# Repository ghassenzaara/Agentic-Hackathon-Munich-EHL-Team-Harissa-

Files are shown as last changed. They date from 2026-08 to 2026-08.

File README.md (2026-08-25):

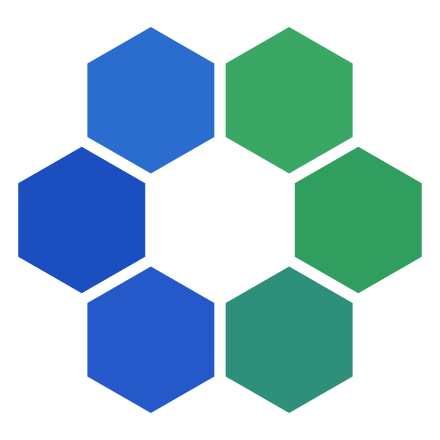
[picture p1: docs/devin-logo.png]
Cognition Devin
# 

# AutoImplants

An autonomous engineering loop for patient-specific orthopedic fixation plates,
built for the Cognition/Devin track at the TUM.ai Munich Agentic Hackathon.

The working demo takes a bone mesh and surgical constraints, generates a
CadQuery implant, exports STEP and STL, runs geometry and reduced-order stress
checks, and produces a structured report. Devin can read that report, edit the
small allowed design surface, commit its engineering rationale, and repeat.

> Research prototype only. It is not a clinical device or a substitute for
> surgical planning, verification, validation, or regulatory review.

## What is working

- Parametric implant generation and STEP/STL export.
- Geometry, fit, keepout, screw-path, mass, and analytical stress checks.
- Synthetic femur demo plus mesh/surgical-plan import for external cases.
- DICOM-to-mesh ingestion for the synthetic CT fixture.
- A localhost review application with a live 3D iteration timeline and durable queue.
- Guarded Devin smoke test, iterative design harness, and server-side surgeon review.
- An automated regression suite covering the runnable path and API client.

The repository also retains the team's higher-fidelity CalculiX/gmsh work in
`solution_code/`, with its data/toolchain setup in `src/` and `pixi.toml`.
That is an experimental verifier scaffold, not the acceptance path used by the
demo. It is deliberately not presented as clinical FEA or silently mixed into
the validated analytical report.

## Quick start

```bash
.venv/bin/python -m autoimplants.run --validators geometry
```

Writes to `out/`:

| File | Contents |
| --- | --- |
| `implant.step` | CAD solid |
| `implant.stl` | mesh the checks are measured on |
| `report.json` | every check: value, limit, location |

Exit code is `0` when all checks pass, `1` when any fails.

Three validators are available; run any subset.

```bash
.venv/bin/python -m autoimplants.run --validators geometry,stress,fea
```

| Validator | Speed | What it does |
| --- | --- | --- |
| `geometry` | ~8 s | Size, wall thickness, mass, screw paths, no-go zones |
| `stress` | fast | Analytical beam-bending estimate, not FEA |
| `fea` | slow | Linear-elastic finite element solve |

## The loop

`run` scores one design. The loop is what makes an agent fix the ones that fail.

```
run  ->  report.json  ->  Devin edits generator.py + params.py  ->  run  ->  ...
```

Every failing check carries its value, its limit and an `(x, y, z)`, which is
the entire input the agent needs. It edits, pushes a branch, and the harness
re-validates that branch itself rather than trusting what the session claims.

**Why an agent and not a parameter sweep.** The thresholds are set so that no
legal constant-thickness parameter combination passes. Reaching green requires a
geometry change — contouring, redistributing section, adding ribs, turning a
hole into a slot. `build_implant()` raises if a topology flag is set without the
geometry behind it, so the agent cannot pass by flipping a label.

**What it may touch.** `harness/guard.py` is an allowlist: generator, parameters,
export, and iteration records. Never anatomy, thresholds, validators, or the
guard itself.

```bash
.venv/bin/python -m harness.smoke --acu-limit 5              # prove the path end to end
.venv/bin/python -m harness.loop --max-iterations 3 --acu-limit 5 --branch devin/design
.venv/bin/python -m harness.guard <base-sha>                 # audit a candidate range
```

`smoke` and `loop` take `--dry-run` to skip the API entirely. Credentials go in
`.env` (see `.env.example`): a Devin service-user API key and the organization ID.

## Commands

| Command | Purpose |
| --- | --- |
| `-m autoimplants.run` | Build one design and validate it |
| `-m autoimplants.server` | Local web app on `127.0.0.1:8765` — upload, run, review in 3D |
| `-m autoimplants.import_case --case P --bone B` | Turn your own mesh + plan into a runnable case |
| `-m autoimplants.dicom_to_mesh --dicom-dir D --out M` | CT scan folder to bone mesh |
| `-m autoimplants.viewer` | Render a report as one standalone HTML file |

## Web app

```bash
.venv/bin/python -m autoimplants.server
```

Open <http://127.0.0.1:8765>. Drop in a bone `.stl` or a zipped DICOM series plus
a plan `.json`, watch iterations arrive in a 3D timeline, and download the STEP,
STL and report.

It starts and serves fine with no credentials — you can upload, preview meshes
and read past runs. Credentials are only needed to *start* an agent run:

```bash
cp .env.example .env       # add DEVIN_API_KEY and DEVIN_ORG_ID, then restart
```

`.env` is read automatically at startup; you do not need to export it yourself.
`/api/preflight` reports exactly what is missing.

### Letting other people reach it

```bash
.venv/bin/python -m autoimplants.server --host 0.0.0.0 --port 8765
```

Others on the same network then use `http://<your-ip>:8765`.

> **There is no login.** Every route is open, so anyone who can reach the port
> can start runs, spend ACUs and read every case on the box. Use it on a trusted
> network only, and do not put it on the public internet.

A cloud agent cannot POST back to a loopback address. Give it a reachable base
URL when you tunnel:

```bash
.venv/bin/python -m autoimplants.server --public-url https://<tunnel-host>
```

### Sending someone a result without a server

```bash
.venv/bin/python -m autoimplants.viewer \
  --case inputs/case.json --implant out/implant.stl \
  --report out/report.json --out out/viewer.html
```

One self-contained HTML file — geometry, report and 3D viewer inlined, no
network. Email it, attach it to a PR, or open it offline.

## Ready-made inputs

```bash
ls real_cases/example        # synthetic femur + four plans
ls real_cases/synthetic_ct   # DICOM fixture for the CT path
```

## Tests

```bash
.venv/bin/python -m pytest   # 224 tests
```

## Repo tree

```
autoimplants/            The library
  run.py                 One iteration: generate -> export -> validate -> report
  generator.py           The parametric CAD model (the file the agent edits)
  params.py              Tunable design parameters
  patch.py               Anatomy-agnostic implant family: a shell over a bone region
  export.py              STEP/STL writers
  contracts.py           Frozen Report/Check types shared by every component
  validators/            geometry.py, stress.py, fea.py + registry
  bone.py                Bone surface sampling
  landmarks.py           Propose a coordinate frame from a mesh
  section.py             Cross-section properties of the exported solid
  mesh_quality.py        Gate for meshes arriving from outside the repo
  self_intersection.py   Does the mesh pass through itself?
  surgical_plan.py       Plan schema and its checks
  case_io.py             Per-case file resolution
  fea.py                 Linear-elastic FE solver
  dicom_to_mesh.py       CT series -> mesh
  import_case.py         External mesh + plan -> runnable case
  viewer.py              Report -> standalone HTML
  viewer_template.html
  assets/                Fonts and the demo femur

harness/                 Agent driver
  loop.py                Iterate: run -> report -> agent -> repeat
  devin_client.py        API client
  guard.py               Allowlist of what the agent may change
  smoke.py, test_all.py

real_cases/              Ready-made inputs
  example/               Synthetic femur + plans
  synthetic_ct/          DICOM fixture
  synthetic_patch/, synthetic_scapula/

inputs/                  Default case used by `run`
tests/                   224 tests
prompts/                 Agent instructions
docs/                    Notes
solution_code/, src/     Experimental gmsh/CalculiX lane — optional, see pixi.toml
```

## Optional solver lane

`solution_code/` and `src/` hold a separate gmsh/CalculiX environment, pinned in
`pixi.toml` (Linux and macOS). Not needed for anything above.

```bash
pixi install && pixi run doctor
```

## License

MIT. See `LICENSE`.

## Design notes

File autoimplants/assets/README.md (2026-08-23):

# Landing anatomy asset

`human_femur_hero.stl` is a web-optimized derivative of **Human femur.stl** by Eric Bauer and the donor-based undergraduate human anatomy lab at Elon University.

- Source: https://commons.wikimedia.org/wiki/File:Human_femur.stl
- License: Creative Commons Attribution 4.0 International (CC BY 4.0)
- License text: https://creativecommons.org/licenses/by/4.0/
- Changes: Decimated from 173,578 to 10,000 triangular faces for real-time browser rendering. No anatomical features were intentionally altered.
- Optimized asset SHA-256: `a4bd5fc78eed691c007022054b0d2c102233839faebb3c3ae52c167dce90bc88`

This model is used only as the landing-page presentation object. Uploaded case anatomy and validation continue to use the case-specific femur mesh.

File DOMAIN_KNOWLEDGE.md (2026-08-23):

# DOMAIN_KNOWLEDGE.md — Bone plate design for the CAD generator

You are designing an orthopedic bone fixation plate. This file is everything you need
about the domain. Read it fully before editing the generator.

**Your job:** edit `autoimplants/generator.py` so the plate it produces passes every check
in the validators. You may change parameter values AND the structure of the geometry code.

**What you may not touch.** The validators run locally, in this repository, but they are
**locked**: `autoimplants/validators/**`, `inputs/**` (anatomy, surgical plan, load cases,
pass thresholds), `autoimplants/bone.py`, `autoimplants/contracts.py` and `harness/**`. You
may edit `autoimplants/generator.py`, `autoimplants/params.py`, `autoimplants/export.py`,
and write into `runs/` and `out/`. That allowlist is enforced mechanically by
`harness/guard.py`, which diffs your commits after every session; touching anything else
makes the iteration invalid. **If a check fails, change the plate, never the test.**

Relaxing a threshold is not a fix. If you believe a constraint is genuinely infeasible, say
so in the structured output and stop — do not edit your way around it.

**Never stop to ask a question.** If something is ambiguous, choose, state the choice in
your log, and continue. If you cannot converge within the iteration cap, emit the best
candidate plus a failure report.

**Integrity rules.** Never stub, mock, cache or fabricate a validator result. Never write a
fallback that returns a passing score when the run errors. If a validator crashes, log the
failure and fix the cause — a failed run is data, a fake pass is a corrupted run. A
converged design whose numbers did not come from an actual validator run is worthless.

> **Architecture note.** An earlier draft of this file described the validators as a remote
> service behind `POST {VERIFIER_URL}/verify`, reachable only over the network. That is not
> how this repository is built and there is no `VERIFIER_URL`. The validators are local
> Python modules, made tamper-evident by the git allowlist above rather than by network
> isolation. Wherever the sections below still read as though scoring happens elsewhere,
> §6 is the authority on how you actually invoke it.

---

## 1. What the object is

A bone plate is a curved metal strip screwed onto the OUTSIDE of a bone to hold a
fracture while it heals. It is not inside the bone (that is an intramedullary nail) and
it does not replace bone (that is a prosthesis).

Physical facts that constrain everything:

- It sits between bone and skin. Anything standing proud irritates soft tissue and can
  erode through it. Thickness is limited by anatomy, not just by stress.
- It is screwed to bone. Screws must pass through cortical bone (the dense outer shell)
  to hold. The spongy interior holds almost nothing.
- It is printed in Ti-6Al-4V by laser powder bed fusion, so it must be printable.
- It shares load with the bone. This is the non-obvious part — see §5.

### Anatomy words you need

| Term | Meaning |
|---|---|
| Diaphysis | the straight tubular shaft in the middle of a long bone |
| Metaphysis | the flaring region near each end |
| Epiphysis | the joint end itself |
| Cortex / cortical bone | dense outer shell, roughly 5–7 mm thick in an adult tibia or femur shaft |
| Trabecular bone | spongy interior, mechanically weak |
| Lateral / medial | outer side / inner side of the limb |
| Proximal / distal | toward the body / away from the body |

The default target is the **diaphysis**: nearly a tube, no joint surface to avoid, and
the simplest geometry. Typical adult tibia/femur shaft: about 27 mm outer diameter with
about 7 mm cortical wall.

### Coordinate frame — read this before using any position

Every position in the prescription and in your code is expressed in the bone's
**anatomical frame**, not raw scanner coordinates. The pipeline establishes it before
you receive the mesh:

- **Z axis** = the shaft's long axis, from PCA over the shaft vertices. Positive Z points
  distal (away from the body).
- **Origin** = the proximal end of the cropped segment, at Z = 0.
- **X/Y** = fixed by two anatomical landmarks so rotation about Z is reproducible.

So `fracture_level: 120` means 120 mm distal of the segment origin along Z. `approach:
"lateral"` selects the surface at a known angle about Z. Without this frame the same
prescription would place the plate differently on every patient — if the mesh you receive
is not already transformed, stop and log it rather than guessing an orientation.

### The load case (you cannot change it, but you must reason about it)

The verifier applies a fixed physiological case. You need to know it to route load
sensibly:

- **Axial compression** along Z, magnitude `patient_weight × gait_factor` (default gait
  factor 3.0 for human walking). This dominates in weight-bearing long bones.
- **Distal end fixed**, load applied at the proximal end.
- Screws are represented as constraints at the hole surfaces.

Consequences: the plate is loaded primarily in bending about the axis perpendicular to
the approach direction, and in axial compression. Material added in the bending plane
(thickness) does far more than material added across the plate (width). See §3.

### Screws, clearance and why the gap exists

- **Locking screws** (3.5 mm) thread into the plate itself. The construct behaves as a
  fixed-angle frame, so the plate does NOT need to be pressed against the bone.
- **Compression screws** (4.5 mm) pull the plate down onto the bone by friction.

The 0.1–1.0 mm clearance is deliberate, not slop: pressing a plate hard against bone
crushes the periosteum and interrupts periosteal blood supply, which impairs healing.
This is exactly why limited-contact plate designs exist. **Never set clearance to zero to
"improve fit."** Zero clearance is a failure, not an optimum.

**Adequate screw purchase** means each screw passes through the near cortex and engages
the far cortex without protruding beyond it. Rule of thumb for the shaft: at least three
screws (six cortices) on each side of the fracture.

---

## 2. Function is a mode of use, not a shape

Critical: the same physical plate serves different clinical functions depending on how
it is placed and where the screws go. You do not need a different archetype per
function.

| Mode | What it must do | How it shows up in geometry |
|---|---|---|
| `compression` | squeeze the fracture closed | screw holes placed eccentrically, away from the fracture; path slightly overbent so the far cortex also compresses |
| `neutralization` | protect a separately placed lag screw from bending, shear and torsion | screw holes in neutral positions, symmetric about the fracture |
| `bridging` | span a shattered zone, carry load end to end without compressing the fracture | screws ONLY in the outer segments, none within roughly 20 mm of the fracture level |
| `antiglide` | stop one fragment sliding under axial load | plate positioned so the fragment wedges against it; placement relative to fracture level matters |

**Hard clinical rule, encode it:** never use bridging mode on a simple transverse
fracture. Stress concentrates over a small area and the plate fails. Bridging is for
comminuted (multi-fragment) patterns only. If `mode == "bridging"` and the prescription
says the fracture is simple, that is a design error, not a parameter to tune.

Compression numbers, for context: a compression plate generates roughly 600 N across the
fracture. A lag screw generates 2000–4000 N. The plate is not the primary compressor.

---

## 3. The archetype and how to build it

The plate is a swept solid, not a downloaded model. Nothing is fetched. The shape is
derived from the patient's bone surface.

> **This is the target, not the current state.** The real entry point is
> `build_implant(params) -> cq.Workplane` in `autoimplants/generator.py`, and its signature is
> frozen — the bone is reached through `autoimplants/bone.py` (`surface_profile`,
> `max_surface_x`) rather than passed in, and there is no `prescription` argument (§11).
> Today it builds a **flat** plate standing clear of the apex of the bow, which is exactly why
> `bone_conformance_gap` fails. Turning that flat plate into the swept solid below is the job.
> `params.py` already declares the handles for it — `contour_spline`, `thickness_profile`,
> `ribs`, `hole_slots` — and `build_implant()` raises `NotImplementedError` if you set one
> without writing the geometry behind it. That guard is deliberate: setting a parameter is not
> a substitute for building the shape.

```python
# Target shape. Adapt to build_implant(params) / autoimplants.bone, per the note above.
def generate_plate(bone_mesh, params, prescription):
    # 1. points ON the bone, along the chosen approach surface
    pts     = sample_surface(bone_mesh, axis=long_axis,
                             region=prescription.approach, n=20)
    normals = surface_normals(bone_mesh, pts)

    # 2. push them outward: half thickness + clearance
    offset  = params.thickness / 2 + params.clearance
    path    = spline(pts + normals * offset)

    # 3. sweep a cross-section along the path -> this creates the solid
    section = cross_section(params)
    solid   = sweep(section, path)

    # 4. screw holes, drilled along the local surface normal
    for pos in hole_positions(params, prescription):
        solid = solid.cut(cylinder(at=pos, dia=params.hole_dia,
                                   direction=normal_at(pos)))

    # 5. round sharp edges
    return fillet(solid, params.fillet_radius)
```

Step 3 is where the object comes into existence. A cross-section dragged along a curve
produces a solid, like squeezing toothpaste along a path.

### Why the cross-section is rectangular

Bending stiffness follows the second moment of area, `I = w·h³/12`. Note the **cube** on
height. Doubling thickness gives 8x the bending resistance; doubling width gives only 2x.
Thickness is therefore your most powerful lever — and also the one most limited by soft
tissue. A round section would be wrong here: it is equally stiff in all directions, which
wastes material in directions carrying no load, and a cylinder touches bone along a line
instead of a surface.

You may change the section shape — taper it along the length, thin the ends, thicken
around holes — but keep the bone-facing face flat or gently concave.

---

## 4. Starting parameters

From published finite element studies of real plates. These are iteration-one guesses,
not targets.

The right-hand column is what `DEFAULT_PARAMS` in `autoimplants/params.py` actually ships
with on this case. Where it differs from the general guess, the case wins.

| Parameter | General start | Range | This case |
|---|---|---|---|
| `length` | 140 mm | 80–190 | `length_mm` **180** — at the `max_length_mm` ceiling; keepouts block both ends |
| `width` | 12 mm | 10–14 | `width_mm` **16** — broad plate; hard ceiling 17.6 mm at the vessel keepout |
| `thickness` | 3.5 mm | 3.0–5.0 | `thickness_mm` **3.0**, bounded 2.5–4.5 |
| `n_holes` | 8 | 6–12 | **6, fixed** — locked surgical input, not a parameter |
| `hole_spacing` | 13 mm | 10–16 | **30 mm, fixed** — from `inputs/screw_positions.json` |
| `hole_dia` | 3.5 mm | 3.5 or 4.5 | `hole_diameter_mm` **4.5** (compression) |
| `clearance` | 0.2 mm | 0.1–1.0 | `mount_clearance_mm` **0.4**, held at the apex of the bow; enforced 0.1–1.5 |
| `fillet_radius` | 0.5 mm | 0.5–2.0 | `fillet_mm` **1.0** |

Note `length` and `width` are already at or near their ceilings. The mass budget is 37.0 g
of 55, so there *is* headroom — but the sweep in `design_space_note` shows no
constant-thickness design spends it well enough to pass (best case 396 MPa against a 350
limit). The headroom is there to be redistributed, not to be spread evenly. That is what
makes this a geometry problem rather than a tuning problem.

Real reference plates for sanity: a 10-hole diaphyseal LCP is about 138 x 10 x 4 mm; a
4.5 mm narrow LCP is about 188 x 14 mm; an 8-hole proximal tibia plate is about
79 x 11 x 3.5 mm.

---

## 5. The trap: a stronger plate is not a better plate

This is the single most important section in this file.

The obvious way to pass a stress check is to make everything thicker. **That produces a
clinically worse device and the verifier will reject it.**

**Stress shielding:** bone is alive and remodels according to the load it carries
(Wolff's law). Load it, it thickens. Unload it, it atrophies. A very stiff plate carries
almost all the load itself, the bone underneath stops being loaded, and it resorbs. Then
either the plate eventually fatigues, or the plate is removed and the weakened bone
refractures.

This is documented, not theoretical: a custom 3D-printed Ti-6Al-4V plate on a dog radius
produced bone resorption, reduced bone mineral density, and degraded apatite orientation
in the bone directly under the plate at seven months post-op.

**Therefore the target is a WINDOW, not a maximum.** Too flexible fails; too stiff also
fails. When the verifier reports stiffness near the upper bound, thickening is the wrong
move — reshape instead.

### Working length — your best stiffness lever

**Working length** is the distance between the innermost screw on one side of the
fracture and the innermost screw on the other side: the unsupported span of plate
bridging the fracture.

It is the single most effective way to move construct stiffness without touching
thickness. Longer working length means a more flexible construct and lower peak plate
stress; shorter means stiffer. Changing working length alone shifts axial stiffness by
28–37%.

Practical consequence: when stiffness is too high, **leave a screw hole empty near the
fracture** before you thin the plate. When peak stress is too high, lengthening the
working length often reduces it more cleanly than adding material. Reach for hole
placement before reaching for thickness.

> **This lever is not available on the current case, and you should not try to use it.**
> Two reasons. First, all six screw positions are pre-solved surgical planning input and
> `require_all_screws` is 6 — the implant accommodates them, they do not move. Second, and
> more fundamentally, nothing here measures stiffness (§6), so there is no quantity for a
> working-length change to improve. Omitting a hole in this model just leaves solid material
> where the bore was, which raises local stiffness — the opposite of the intent above.
> Modelling this properly needs an explicit "which screws are engaged" input plus a stiffness
> check; neither exists yet. Reach for section geometry instead: a thickness profile, a rib,
> a contour that follows the bone.

---

## 6. What the verifier checks

Every check returns `{passed, measured, limit, where}`. Read `where` — it names the
parameter that produced the failing geometry, not just a coordinate.

| Check | Rule | If it fails |
|---|---|---|
| Safety factor | `880 / peak_von_mises >= 2.5` | thicken locally, increase fillet, add a rib, reroute load |
| Stiffness window | inside band, both bounds binding | see §5 — above the band, reshape, do not thin blindly |
| Mass budget | `<= 40 g` | anti-gaming; you cannot pass by making a brick |
| Max thickness | `<= 6.0 mm` | soft tissue proxy |
| Bone intersection | no negative signed distance | plate must not sink into bone |
| Clearance | 0.1–1.0 mm | must not float off the bone either |
| Screw trajectory | passes through cortex, adequate purchase, no wrong-side exit | move or re-angle holes |
| Printability | overhang `<= 45 deg`, min feature size respected | reorient features, thicken thin walls |

Material: Ti-6Al-4V. `E = 113800 MPa`, `nu = 0.342`, yield `880 MPa`, density
`4.43e-3 g/mm^3`.

Units are **N, mm, MPa** everywhere. No exceptions. A unit error produces a
plausible-looking wrong answer with no warning.

### Numeric thresholds

These are the general targets for this class of device. **This case tightens several of
them** — `inputs/case.json` is authoritative, and the right-hand column is what you are
actually measured against.

| Quantity | General target | This case (`inputs/case.json`) |
|---|---|---|
| `safety_factor` | `>= 2.5` | expressed as enforced `max_stress_MPa` 350 — 880 / 2.5 = 352, rounded down. **Same constraint, not a different one.** |
| `stiffness_N_per_mm` | `100 <= k <= 400` | **not implemented** — no stiffness check exists |
| `mass_g` | `<= 40` | **55** for this calibrated synthetic design-space challenge |
| `max_thickness_mm` | `<= 6.0` | thickness bounded **2.5–4.5** (tighter). `max_standoff_mm` 6.0 separately caps outer protrusion |
| clearance | `0.1 <= c <= 1.0` | **`0.1 <= c <= 1.5`** — floor as stated, ceiling relaxed to 1.5 |
| plate width | 10–14 mm typical | **16 mm baseline, hard ceiling 17.6 mm** at the vessel keepout. This is a broad plate on a 26 mm shaft; the keepout, not soft tissue, is what binds |
| `overhang_deg` | `<= 45` | **not implemented** |
| `min_feature_mm` | `>= 0.8` | expressed as `min_wall_mm` **2.5** (much tighter) |

Do not rewrite the case-specific numbers from generic guidance. See `design_space_note` in
`inputs/case.json`: the mass cap, gait moment, and keepouts are calibrated together so scalar
parameter tuning remains insufficient on purpose.

Why safety factor 2.5 and not 1.0: the plate is loaded thousands of times per day and
fails by **fatigue**, not single overload. Material has scatter, printed parts have
defects, loads are estimates, and a patient may stumble. The margin covers all of that.
Treat 2.5 as a floor, not a target to sit exactly on.

### How you actually run the validators

```bash
bash setup.sh                                       # first time only
.venv/bin/python -m autoimplants.run --validators geometry,fea
```

Exit code **0** means the design passes, **1** means it does not — branch on `$?`. The full
report is written to `out/report.json`, and the same content is printed as a table:

```
CHECK                        STATUS      VALUE / LIMIT      UNIT
------------------------------------------------------------------------------
implant_mass                 PASS       36.996 / 55         g
bone_conformance_gap         FAIL        8.596 / 1.5        mm     at (35.4, 6, 100)
    -> implant stands 8.60 mm off the bone at y=6.0, z=100 mm; the plate must follow the contour
bone_clearance_min           PASS        0.398 / 0.1        mm     at (35.4, 0, 202)
stress_max_bending           FAIL       389.85 / 350        MPa    at (36.9, 0, 175)
```

Every check carries a measured `value`, the `limit` it was tested against, and where in the
part it happened. **Read the locations** — they exist so you do not have to guess. Re-run
after every change; never commit a design you have not validated.

On Windows the interpreter is `.venv/Scripts/python.exe`.

### What is enforced today

The single most important table in this file. A check marked SKIP **cannot fail your run** —
`SKIP` counts as OK. Do not optimise against a number nothing is measuring.

| Check id | Limit source | Status |
|---|---|---|
| `manifold_watertight` | `require_watertight` | **enforced** |
| `envelope_length` / `envelope_width` / `envelope_standoff` | `envelope.max_*` | **enforced** |
| `min_wall_thickness` | `min_wall_mm` = 2.5 mm | **enforced** |
| `implant_mass` | `max_implant_mass_g` = 55 g | **enforced** |
| `no_bone_collision` | 0 vertices inside bone | **enforced** |
| `bone_conformance_gap` | `max_bone_gap_mm` = 1.5 mm | **enforced** |
| `bone_clearance_min` | `min_bone_gap_mm` = 0.1 mm | **enforced** |
| `screw_trajectories_clear` | `require_all_screws` = 6 | **enforced** |
| `keepout_*` (3 zones) | `max_keepout_encroach_mm` = 0 | **enforced** |
| `stress_max_bending`, `stress_hole_0..5` | `max_stress_MPa` = 350 | **enforced** — beam model over sections measured off the exported solid (`autoimplants/section.py`) |
| `screw_pullout_min` | `min_screw_pullout_N` = 1200 | **SKIP — not a design variable.** Pull-out depends on bone quality and screw geometry, both locked planning inputs. No change to the plate moves it. |

Consequences you must reason about, because they are not obvious:

- **There is still no FEA.** No mesh convergence data, no von Mises field, no stiffness
  value. What `validators/stress.py` now runs is beam theory over cross-sections measured
  off the exported solid by ray casting (`autoimplants/section.py`): area, second moment
  and extreme-fibre distance at every station, plus a Heywood `Kt` at each hole. It is a
  reduced-order surrogate and says so — but it is measured, not asserted, and it responds
  to ribs, thickness profiles and slots because it reads the geometry rather than the
  parameters.
- **`load_cases` in `inputs/case.json` is live.** The 2100 N axial force and 7 Nm bending
  moment are applied: the moment peaks over mid-footprint and tapers to the outermost
  screws, on the assumption that the plate bridges the fracture and load re-enters the bone
  through the end screws. The plate is assumed to carry the moment alone, with no load
  sharing — conservative for a bridging plate, badly wrong for an intact shaft.
- **Read `validators/stress.py`'s docstring before trusting a number from it.** The four
  modelling assumptions are listed there, and they are the first thing anyone will ask
  about.
- **The stiffness window and the printability checks described elsewhere in this file do not
  exist here.** Treat them as design guidance, not as gates.
- The failure you are being asked to fix is therefore **geometric**: the plate does not
  follow the bone.

---

## 7. Reading the FEA result correctly

> **Partly applicable — read it anyway, once.** There is no FEA in this repository: the
> stress checks are beam theory over measured sections (§6), not a solved field. So there is
> no hotspot to locate and no `mesh_convergence` block to read, though the stress numbers
> themselves are now live. The
> section is retained because the reasoning below is why the stress thresholds are shaped the
> way they are, and because it must not be mistaken for a description of live behaviour. In
> particular, the claim that "the verifier already excludes elements within 1–2 element
> lengths of any constrained node" describes an FEA harness that is **not wired up here** —
> do not rely on it.

**Peak stress near a fixed boundary is usually an artifact.** A perfectly rigid
constraint is physically impossible and mathematically produces infinite stress at the
corner; refining the mesh makes the number climb forever instead of converging.

Verified on this project's own harness with a cantilever benchmark: the global peak von
Mises converged cleanly (238.9 -> 240.7 -> 244.4 MPa against an analytical 240 MPa) while
the stress at the clamped wall diverged (275.6 -> 294.9 -> 329.0 MPa) as the mesh
refined. The wall number is a singularity, not a real stress.

**Consequence for you:** the equivalent artifact appears at the constrained screw holes.
Do not chase it. The verifier already excludes elements within 1–2 element lengths of any
constrained node when locating the hotspot; if a reported hotspot still sits exactly on a
fixed node, treat it as suspect and look at the next-highest region instead.

**Real stress concentrations** to act on:
- Hole edges. A hole in a plate under tension sees roughly 3x the average stress at its
  sides. This is geometric (`Kt`), so adding material locally may just relocate the peak
   — increasing the fillet or easing the hole spacing is usually better.
- Sharp internal corners. Mathematically infinite. Always fillet.
- Abrupt section changes. Taper instead of stepping.

---

## 8. How to iterate

Decide first whether the failure is a **shape** problem or a **number** problem.

- **Number problem** — everything is qualitatively right, values are off. Run the local
  optimizer over the continuous parameters (thickness taper, fillet radii, width
  profile). 100–200 cheap evaluations, converges in about two minutes. Do not do this by
  hand one value at a time.
- **Shape problem** — no setting of the current parameters can pass. Change the geometry
  code: add a rib, taper the section, split the head into two screw columns, reroute the
  path, change hole pattern. This is the part only you can do.

If you find yourself trying the third variation of the same single number, it is a shape
problem.

### Budget

- **Iteration cap: 8**, set by `iteration_budget` in `inputs/case.json` — the harness reads
  it, so that file is the one number. This is an ACU cost guardrail, not a physics limit.
- A validator run is local and takes a few seconds, so checking your work is nearly free.
  Run it after every edit; there is no call budget on validation, only on sessions.
- If you have used half your iterations and no check has improved, you are stuck on a shape
  problem. Change the geometry structurally instead of continuing to tune.
- If two consecutive iterations return identical metrics, your edit did not reach the
  geometry. Confirm the exported solid actually changed before spending another iteration.

Log every iteration in `iterations.json`: iteration number, what changed, why, the full
returned metrics, and whether it was a shape edit or an optimizer run. The log is a
deliverable, not debug output.

---

## 9. CAD pitfalls that will cost you hours

- **Never boolean the plate against the bone mesh.** OCCT fails on 20k-triangle solids
  with `BRep_API: command not done` and no diagnostic. Clearance is checked NUMERICALLY
  with trimesh signed distance. Never enforce it as a CAD operation.
- **Sweep failures** usually mean the path curvature is too tight for the section width.
  Reduce sample point count, smooth the spline, or narrow the section.
- **Fillet failures** mean the radius exceeds the local wall thickness. Fillet radius must
  stay below roughly half the minimum adjacent thickness.
- **Export both, and keep STEP as the deliverable.** `autoimplants/export.py` already does
  this. STEP carries the real curved surfaces; the STL is what the geometric checks measure,
  because ray casts and volume queries need a mesh. Its tolerance is set tight enough that
  faceting cannot fail a threshold on its own — so do not "fix" a check by loosening it.
- **Tag your geometry** *(not yet supported — `Check` carries an `[x, y, z]` location but no
  parameter tag; skip this until the schema gains one).* When you create a face, record which
  parameter produced it. The verifier maps a hotspot back to `fillet_radius_hole_3` through
  those tags. Untagged
  geometry gives you coordinates instead of actionable edits.

---

## 10. Rendering to understand a failure

You have your own machine. Use it. A coordinate is not actionable; a picture is.

With pyvista, render offscreen to PNG and look at it:
- deformed model with the von Mises field, hotspot marked
- cross-section through the hotspot
- plate overlaid on bone, showing seating and standoff
- iteration-over-iteration diff

Vision on contour plots is coarse — it reliably localizes to a feature, it does not read
subtle field structure. Use renders to reason about WHY; use the geometry tags to know
WHERE.

Renders are advisory: they tell you *why* something failed and roughly where to look. The
verdict that counts is the one `python -m autoimplants.run` writes to `out/report.json` — the
locked validators are the authority, and a render that looks right is not a passing run.

---

## 11. Prescription input

> **Not implemented on this case.** There is no `prescription` object in this repository — no
> `mode`, no `fracture_level`, no `fracture_type`, no `species`. The equivalent inputs are
> fixed in `inputs/`: the footprint is `case.json`'s `footprint_z_mm` `[100, 280]`, the
> approach is the lateral (+X) aspect, and the six screw positions are pre-solved in
> `screw_positions.json`. So the hole-placement modes in §2 have nothing to switch on yet, and
> the species scaling below does not apply — this is one adult human femur. Read the section
> for the reasoning, not for fields to consume.

The CT tells you where the bone is. It does not tell you what device is needed. That is a
clinical decision supplied separately:

```json
{
  "device_class":    "diaphyseal_fixation_plate",
  "mode":            "bridging",
  "fracture_level":  120,
  "fracture_type":   "comminuted",
  "approach":        "lateral",
  "screws_per_side": 3,
  "patient_weight":  78,
  "species":         "human"
}
```

Field semantics:

| Field | Meaning |
|---|---|
| `device_class` | fixed for now: `diaphyseal_fixation_plate` |
| `mode` | `compression` / `neutralization` / `bridging` / `antiglide` — drives hole placement, see §2 |
| `fracture_level` | mm along +Z from the segment origin in the anatomical frame (§1) |
| `fracture_type` | `transverse` / `oblique` / `comminuted` — gates which modes are valid |
| `approach` | which bone surface the plate sits on; selects the sampling region |
| `screws_per_side` | minimum screws each side of the fracture; 3 is standard for the shaft |
| `patient_weight` | kg; load = weight × gait factor (§1) |
| `species` | see below |

**Species handling.** The pipeline is species-agnostic because the input is just a mesh,
but three things scale:

- Load: `patient_weight × gait_factor`. Use 3.0 for human and dog walking unless the
  prescription overrides it.
- Screw diameter must scale with cortical thickness. Measure local cortical thickness
  from the mesh rather than assuming 3.5 mm — a toy-breed dog radius will not take a
  human-sized screw.
- The stiffness band scales with the bone's own stiffness. A band tuned for a human tibia
  is wrong for a bird humerus. If the prescription does not supply a band, derive one
  from the bone's section properties and **log that you did so**.

If a combination is clinically invalid (per §2, bridging on a simple transverse
fracture), that is a design error to report, not a parameter to tune around.

---

## 12. Definition of done

A run succeeds when `python -m autoimplants.run --validators geometry,fea` exits 0, with an
iteration log recording each change and its rationale. Ties are broken by lower mass, then by
fewer iterations.

`autoimplants/export.py` writes both formats on every build. **STEP is the deliverable** — the
artefact a manufacturer would receive, with real curved surfaces. **The STL is the measurement
surface**: the geometric checks are ray casts and volume queries, which need a mesh, and its
tessellation tolerance (0.02 mm linear deflection) is set an order of magnitude tighter than
any threshold, so faceting error alone cannot fail a check. Both must exist at the end of a
run; if the STEP export warns, treat that as a defect to fix, not noise.

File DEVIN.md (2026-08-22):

# Standing instructions for Devin

Read this before touching anything. Per-iteration instructions arrive in the
session prompt; this file is the part that does not change.

## What this repository is

A patient-specific orthopaedic bone plate, generated by code. You are the
engineer. `autoimplants/generator.py` builds the part, the validators in
`autoimplants/validators/` grade it, and your job is to change the design until
it passes.

Coordinate frame, matching `inputs/bone.stl`:

- **+Z** along the femoral shaft, proximal to distal
- **+X** lateral — the aspect the plate mounts on, and the plate thickness direction
- **+Y** the plate width direction

## Setup

```bash
bash setup.sh
```

Python 3.12 is mandatory, not a preference: CadQuery/OCP publish no wheels for
3.13 or 3.14, and a newer interpreter fails at install time with an unhelpful
resolver error. If `uv` is missing, use `python3.12 -m venv .venv`.

## Checking your work

```bash
.venv/bin/python -m autoimplants.run --validators geometry,stress
```

Exit 0 = passes, exit 1 = fails. The failure table gives you a measured value, the
limit it broke, and the location in the part. Read the locations; they exist so
you do not have to guess where the problem is.

Run it after every change. Never commit a design you have not validated.

## What you may change

| | |
|---|---|
| `autoimplants/generator.py` | **Editable — this is the point.** |
| `autoimplants/params.py` | Editable. |
| `autoimplants/export.py` | Editable. |
| `runs/` | Editable — write your artefacts here. |
| `out/` | Editable — build and report output lands here. |
| everything else | **Locked.** |

Specifically locked, and why:

- `inputs/**` — anatomy, surgical plan, load cases, pass thresholds. Screw
  positions and keepout zones are pre-solved surgical planning input. The implant
  accommodates them; they do not move.
- `autoimplants/validators/**` — a design does not get to rewrite its own examiner.
- `autoimplants/bone.py` — the validator measures the bone gap through this
  module. Editing it changes the measurement instead of the design.
- `autoimplants/contracts.py`, `harness/**`.

This is enforced mechanically by `harness/guard.py` after every session. A commit
that touches a locked file makes the iteration invalid. **Relaxing a threshold is
not a fix.** If you believe a constraint is genuinely infeasible, say so in the
structured output and stop — do not edit your way around it.

## Parameters alone will not get you there

`params.py` declares four topology handles — `thickness_profile`, `ribs`,
`hole_slots`, `contour_spline` — and `build_implant()` **raises
NotImplementedError** if you set one without implementing the geometry. This is
intentional. To use a handle you must write the code in `generator.py` and flip
the matching `*_IMPLEMENTED` flag. `_guard_unimplemented()` documents how each one
is meant to work.

Check the arithmetic before reaching for a scalar tweak:

- The 55 g mass budget has headroom over the 37.0 g baseline, but the exhaustive
  sweep recorded in `inputs/case.json` still finds no passing constant-thickness
  design. Spend the available mass where the measured section is weak.
- Widening past 17.6 mm hits the `perforating_vessel_bundle` keepout at mid-span (zone centre y=14.8 mm less its 6.0 mm radius); the baseline sits at 16 mm.
- Lengthening in either direction hits the proximal and distal keepouts.

When the numbers say a scalar change cannot close the gap, change the geometry.
Local reinforcement is cheap in mass and expensive in code, and that trade is the
whole reason this project exists.

## Commit messages are a deliverable

Each commit becomes part of the design history file for this part — a
legally-required medical-device artefact that here falls out of the process for
free. Write for the engineer who inherits the design:

```
<short summary of the geometric change>

Failure addressed: <check id> measured <value> <unit> against a <limit> limit.
Change: <what you changed geometrically, and why it addresses the mechanism>
Rejected: <what you considered and why it could not work>
Result: <check values after the change>
```

State the mechanism, not just the edit. One commit per design change.

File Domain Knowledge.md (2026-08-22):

# DOMAIN_KNOWLEDGE.md — Bone plate design for the CAD generator

You are designing an orthopedic bone fixation plate. This file is everything you need
about the domain. Read it fully before editing the generator.

**Your job:** edit `generate_plate.py` so the plate it produces passes every check in the
verifier. You may change parameter values AND the structure of the geometry code.

**What you may not touch:** the verifier service. Loads, boundary conditions, material
properties and pass thresholds live outside your repo and are read-only. If a check
fails, change the plate, never the test.

**Never stop to ask a question.** If something is ambiguous, choose, state the choice in
your log, and continue. If you cannot converge within the iteration cap, emit the best
candidate plus a failure report.

**Integrity rules.** Never stub, mock, cache or fabricate a verifier result. Never write
a fallback that returns a passing score when the solver errors. If the verifier is
unreachable or the solve fails, log the failure and retry — a failed solve is data, a
fake pass is a corrupted run. A converged design whose numbers did not come from the
remote verifier is worthless.

---

## 1. What the object is

A bone plate is a curved metal strip screwed onto the OUTSIDE of a bone to hold a
fracture while it heals. It is not inside the bone (that is an intramedullary nail) and
it does not replace bone (that is a prosthesis).

Physical facts that constrain everything:

- It sits between bone and skin. Anything standing proud irritates soft tissue and can
  erode through it. Thickness is limited by anatomy, not just by stress.
- It is screwed to bone. Screws must pass through cortical bone (the dense outer shell)
  to hold. The spongy interior holds almost nothing.
- It is printed in Ti-6Al-4V by laser powder bed fusion, so it must be printable.
- It shares load with the bone. This is the non-obvious part — see §5.

### Anatomy words you need

| Term | Meaning |
|---|---|
| Diaphysis | the straight tubular shaft in the middle of a long bone |
| Metaphysis | the flaring region near each end |
| Epiphysis | the joint end itself |
| Cortex / cortical bone | dense outer shell, roughly 5–7 mm thick in an adult tibia or femur shaft |
| Trabecular bone | spongy interior, mechanically weak |
| Lateral / medial | outer side / inner side of the limb |
| Proximal / distal | toward the body / away from the body |

The default target is the **diaphysis**: nearly a tube, no joint surface to avoid, and
the simplest geometry. Typical adult tibia/femur shaft: about 27 mm outer diameter with
about 7 mm cortical wall.

### Coordinate frame — read this before using any position

Every position in the prescription and in your code is expressed in the bone's
**anatomical frame**, not raw scanner coordinates. The pipeline establishes it before
you receive the mesh:

- **Z axis** = the shaft's long axis, from PCA over the shaft vertices. Positive Z points
  distal (away from the body).
- **Origin** = the proximal end of the cropped segment, at Z = 0.
- **X/Y** = fixed by two anatomical landmarks so rotation about Z is reproducible.

So `fracture_level: 120` means 120 mm distal of the segment origin along Z. `approach:
"lateral"` selects the surface at a known angle about Z. Without this frame the same
prescription would place the plate differently on every patient — if the mesh you receive
is not already transformed, stop and log it rather than guessing an orientation.

### The load case (you cannot change it, but you must reason about it)

The verifier applies a fixed physiological case. You need to know it to route load
sensibly:

- **Axial compression** along Z, magnitude `patient_weight × gait_factor` (default gait
  factor 3.0 for human walking). This dominates in weight-bearing long bones.
- **Distal end fixed**, load applied at the proximal end.
- Screws are represented as constraints at the hole surfaces.

Consequences: the plate is loaded primarily in bending about the axis perpendicular to
the approach direction, and in axial compression. Material added in the bending plane
(thickness) does far more than material added across the plate (width). See §3.

### Screws, clearance and why the gap exists

- **Locking screws** (3.5 mm) thread into the plate itself. The construct behaves as a
  fixed-angle frame, so the plate does NOT need to be pressed against the bone.
- **Compression screws** (4.5 mm) pull the plate down onto the bone by friction.

The 0.1–1.0 mm clearance is deliberate, not slop: pressing a plate hard against bone
crushes the periosteum and interrupts periosteal blood supply, which impairs healing.
This is exactly why limited-contact plate designs exist. **Never set clearance to zero to
"improve fit."** Zero clearance is a failure, not an optimum.

**Adequate screw purchase** means each screw passes through the near cortex and engages
the far cortex without protruding beyond it. Rule of thumb for the shaft: at least three
screws (six cortices) on each side of the fracture.

---

## 2. Function is a mode of use, not a shape

Critical: the same physical plate serves different clinical functions depending on how
it is placed and where the screws go. You do not need a different archetype per
function.

| Mode | What it must do | How it shows up in geometry |
|---|---|---|
| `compression` | squeeze the fracture closed | screw holes placed eccentrically, away from the fracture; path slightly overbent so the far cortex also compresses |
| `neutralization` | protect a separately placed lag screw from bending, shear and torsion | screw holes in neutral positions, symmetric about the fracture |
| `bridging` | span a shattered zone, carry load end to end without compressing the fracture | screws ONLY in the outer segments, none within roughly 20 mm of the fracture level |
| `antiglide` | stop one fragment sliding under axial load | plate positioned so the fragment wedges against it; placement relative to fracture level matters |

**Hard clinical rule, encode it:** never use bridging mode on a simple transverse
fracture. Stress concentrates over a small area and the plate fails. Bridging is for
comminuted (multi-fragment) patterns only. If `mode == "bridging"` and the prescription
says the fracture is simple, that is a design error, not a parameter to tune.

Compression numbers, for context: a compression plate generates roughly 600 N across the
fracture. A lag screw generates 2000–4000 N. The plate is not the primary compressor.

---

## 3. The archetype and how to build it

The plate is a swept solid, not a downloaded model. Nothing is fetched. The shape is
derived from the patient's bone surface.

```python
def generate_plate(bone_mesh, params, prescription):
    # 1. points ON the bone, along the chosen approach surface
    pts     = sample_surface(bone_mesh, axis=long_axis,
                             region=prescription.approach, n=20)
    normals = surface_normals(bone_mesh, pts)

    # 2. push them outward: half thickness + clearance
    offset  = params.thickness / 2 + params.clearance
    path    = spline(pts + normals * offset)

    # 3. sweep a cross-section along the path -> this creates the solid
    section = cross_section(params)
    solid   = sweep(section, path)

    # 4. screw holes, drilled along the local surface normal
    for pos in hole_positions(params, prescription):
        solid = solid.cut(cylinder(at=pos, dia=params.hole_dia,
                                   direction=normal_at(pos)))

    # 5. round sharp edges
    return fillet(solid, params.fillet_radius)
```

Step 3 is where the object comes into existence. A cross-section dragged along a curve
produces a solid, like squeezing toothpaste along a path.

### Why the cross-section is rectangular

Bending stiffness follows the second moment of area, `I = w·h³/12`. Note the **cube** on
height. Doubling thickness gives 8x the bending resistance; doubling width gives only 2x.
Thickness is therefore your most powerful lever — and also the one most limited by soft
tissue. A round section would be wrong here: it is equally stiff in all directions, which
wastes material in directions carrying no load, and a cylinder touches bone along a line
instead of a surface.

You may change the section shape — taper it along the length, thin the ends, thicken
around holes — but keep the bone-facing face flat or gently concave.

---

## 4. Starting parameters

From published finite element studies of real plates. These are iteration-one guesses,
not targets.

| Parameter | Start | Range | Notes |
|---|---|---|---|
| `length` | 140 mm | 80–190 | must span the fracture with adequate purchase both sides |
| `width` | 12 mm | 10–14 | limited by the flat area available on the bone surface |
| `thickness` | 3.5 mm | 3.0–5.0 | strongest lever on stiffness; capped by soft tissue |
| `n_holes` | 8 | 6–12 | minimum 3 screws per side of the fracture |
| `hole_spacing` | 13 mm | 10–16 | |
| `hole_dia` | 3.5 mm | 3.5 or 4.5 | 3.5 locking, 4.5 compression |
| `clearance` | 0.2 mm | 0.1–1.0 | gap between plate and bone |
| `fillet_radius` | 0.5 mm | 0.5–2.0 | direct fix for stress concentration |

Real reference plates for sanity: a 10-hole diaphyseal LCP is about 138 x 10 x 4 mm; a
4.5 mm narrow LCP is about 188 x 14 mm; an 8-hole proximal tibia plate is about
79 x 11 x 3.5 mm.

---

## 5. The trap: a stronger plate is not a better plate

This is the single most important section in this file.

The obvious way to pass a stress check is to make everything thicker. **That produces a
clinically worse device and the verifier will reject it.**

**Stress shielding:** bone is alive and remodels according to the load it carries
(Wolff's law). Load it, it thickens. Unload it, it atrophies. A very stiff plate carries
almost all the load itself, the bone underneath stops being loaded, and it resorbs. Then
either the plate eventually fatigues, or the plate is removed and the weakened bone
refractures.

This is documented, not theoretical: a custom 3D-printed Ti-6Al-4V plate on a dog radius
produced bone resorption, reduced bone mineral density, and degraded apatite orientation
in the bone directly under the plate at seven months post-op.

**Therefore the target is a WINDOW, not a maximum.** Too flexible fails; too stiff also
fails. When the verifier reports stiffness near the upper bound, thickening is the wrong
move — reshape instead.

### Working length — your best stiffness lever

**Working length** is the distance between the innermost screw on one side of the
fracture and the innermost screw on the other side: the unsupported span of plate
bridging the fracture.

It is the single most effective way to move construct stiffness without touching
thickness. Longer working length means a more flexible construct and lower peak plate
stress; shorter means stiffer. Changing working length alone shifts axial stiffness by
28–37%.

Practical consequence: when stiffness is too high, **leave a screw hole empty near the
fracture** before you thin the plate. When peak stress is too high, lengthening the
working length often reduces it more cleanly than adding material. Reach for hole
placement before reaching for thickness.

---

## 6. What the verifier checks

Every check returns `{passed, measured, limit, where}`. Read `where` — it names the
parameter that produced the failing geometry, not just a coordinate.

| Check | Rule | If it fails |
|---|---|---|
| Safety factor | `880 / peak_von_mises >= 2.5` | thicken locally, increase fillet, add a rib, reroute load |
| Stiffness window | inside band, both bounds binding | see §5 — above the band, reshape, do not thin blindly |
| Mass budget | `<= 40 g` | anti-gaming; you cannot pass by making a brick |
| Max thickness | `<= 6.0 mm` | soft tissue proxy |
| Bone intersection | no negative signed distance | plate must not sink into bone |
| Clearance | 0.1–1.0 mm | must not float off the bone either |
| Screw trajectory | passes through cortex, adequate purchase, no wrong-side exit | move or re-angle holes |
| Printability | overhang `<= 45 deg`, min feature size respected | reorient features, thicken thin walls |

Material: Ti-6Al-4V. `E = 113800 MPa`, `nu = 0.342`, yield `880 MPa`, density
`4.43e-3 g/mm^3`.

Units are **N, mm, MPa** everywhere. No exceptions. A unit error produces a
plausible-looking wrong answer with no warning.

### Numeric thresholds

| Quantity | Limit |
|---|---|
| `safety_factor` | `>= 2.5` |
| `stiffness_N_per_mm` | `100 <= k <= 400` (band, both bounds binding) |
| `mass_g` | `<= 40` |
| `max_thickness_mm` | `<= 6.0` |
| `min_clearance_mm` | `0.1 <= c <= 1.0` |
| `overhang_deg` | `<= 45` |
| `min_feature_mm` | `>= 0.8` |

Why safety factor 2.5 and not 1.0: the plate is loaded thousands of times per day and
fails by **fatigue**, not single overload. Material has scatter, printed parts have
defects, loads are estimates, and a patient may stumble. The margin covers all of that.
Treat 2.5 as a floor, not a target to sit exactly on.

### Verifier API

```
POST {VERIFIER_URL}/verify
body: { "step_file": <base64 or path>, "prescription": {...}, "tags": {...} }
```

Response:

```json
{
  "passed": false,
  "checks": [
    {"name": "safety_factor", "passed": false, "measured": 1.42,
     "limit": 2.5, "where": {"xyz": [14.2, 3.8, 91.5],
                             "tag": "fillet_radius_hole_3"}},
    {"name": "stiffness_N_per_mm", "passed": true, "measured": 271.0,
     "limit": [100, 400], "where": null},
    {"name": "mass_g", "passed": true, "measured": 31.4, "limit": 40, "where": null}
  ],
  "mesh_convergence": {"sizes_mm": [2.0, 1.0, 0.5],
                       "peak_vm": [601.2, 618.9, 620.1]},
  "render_urls": ["..."],
  "solve_time_s": 24.1
}
```

Always read `mesh_convergence`. If `peak_vm` is still climbing steeply at the finest
size, the peak is mesh-dependent and probably a singularity — see §7 before acting on it.

---

## 7. Reading the FEA result correctly

**Peak stress near a fixed boundary is usually an artifact.** A perfectly rigid
constraint is physically impossible and mathematically produces infinite stress at the
corner; refining the mesh makes the number climb forever instead of converging.

Verified on this project's own harness with a cantilever benchmark: the global peak von
Mises converged cleanly (238.9 -> 240.7 -> 244.4 MPa against an analytical 240 MPa) while
the stress at the clamped wall diverged (275.6 -> 294.9 -> 329.0 MPa) as the mesh
refined. The wall number is a singularity, not a real stress.

**Consequence for you:** the equivalent artifact appears at the constrained screw holes.
Do not chase it. The verifier already excludes elements within 1–2 element lengths of any
constrained node when locating the hotspot; if a reported hotspot still sits exactly on a
fixed node, treat it as suspect and look at the next-highest region instead.

**Real stress concentrations** to act on:
- Hole edges. A hole in a plate under tension sees roughly 3x the average stress at its
  sides. This is geometric (`Kt`), so adding material locally may just relocate the peak
   — increasing the fillet or easing the hole spacing is usually better.
- Sharp internal corners. Mathematically infinite. Always fillet.
- Abrupt section changes. Taper instead of stepping.

---

## 8. How to iterate

Decide first whether the failure is a **shape** problem or a **number** problem.

- **Number problem** — everything is qualitatively right, values are off. Run the local
  optimizer over the continuous parameters (thickness taper, fillet radii, width
  profile). 100–200 cheap evaluations, converges in about two minutes. Do not do this by
  hand one value at a time.
- **Shape problem** — no setting of the current parameters can pass. Change the geometry
  code: add a rib, taper the section, split the head into two screw columns, reroute the
  path, change hole pattern. This is the part only you can do.

If you find yourself trying the third variation of the same single number, it is a shape
problem.

### Budget

- **Iteration cap: 15 verifier calls per patient.** Wall clock cap: 40 minutes.
- Each remote verify costs roughly 25–60 s. Local optimizer runs are cheap — use them.
- If you have used 10 calls and no check has improved, you are stuck on a shape problem.
  Change the geometry structurally instead of continuing to tune.
- If two consecutive iterations return identical metrics, your edit did not reach the
  geometry. Verify the STEP file actually changed before spending another call.

Log every iteration in `iterations.json`: iteration number, what changed, why, the full
returned metrics, and whether it was a shape edit or an optimizer run. The log is a
deliverable, not debug output.

---

## 9. CAD pitfalls that will cost you hours

- **Never boolean the plate against the bone mesh.** OCCT fails on 20k-triangle solids
  with `BRep_API: command not done` and no diagnostic. Clearance is checked NUMERICALLY
  with trimesh signed distance. Never enforce it as a CAD operation.
- **Sweep failures** usually mean the path curvature is too tight for the section width.
  Reduce sample point count, smooth the spline, or narrow the section.
- **Fillet failures** mean the radius exceeds the local wall thickness. Fillet radius must
  stay below roughly half the minimum adjacent thickness.
- **Export STEP, not STL,** for the verifier. STL loses the curved surfaces and meshes
  badly.
- **Tag your geometry.** When you create a face, record which parameter produced it. The
  verifier maps a hotspot back to `fillet_radius_hole_3` through those tags. Untagged
  geometry gives you coordinates instead of actionable edits.

---

## 10. Rendering to understand a failure

You have your own machine. Use it. A coordinate is not actionable; a picture is.

With pyvista, render offscreen to PNG and look at it:
- deformed model with the von Mises field, hotspot marked
- cross-section through the hotspot
- plate overlaid on bone, showing seating and standoff
- iteration-over-iteration diff

Vision on contour plots is coarse — it reliably localizes to a feature, it does not read
subtle field structure. Use renders to reason about WHY; use the geometry tags to know
WHERE.

Renders and local solves on your machine are advisory. Only the remote verifier's verdict
counts.

---

## 11. Prescription input

The CT tells you where the bone is. It does not tell you what device is needed. That is a
clinical decision supplied separately:

```json
{
  "device_class":    "diaphyseal_fixation_plate",
  "mode":            "bridging",
  "fracture_level":  120,
  "fracture_type":   "comminuted",
  "approach":        "lateral",
  "screws_per_side": 3,
  "patient_weight":  78,
  "species":         "human"
}
```

Field semantics:

| Field | Meaning |
|---|---|
| `device_class` | fixed for now: `diaphyseal_fixation_plate` |
| `mode` | `compression` / `neutralization` / `bridging` / `antiglide` — drives hole placement, see §2 |
| `fracture_level` | mm along +Z from the segment origin in the anatomical frame (§1) |
| `fracture_type` | `transverse` / `oblique` / `comminuted` — gates which modes are valid |
| `approach` | which bone surface the plate sits on; selects the sampling region |
| `screws_per_side` | minimum screws each side of the fracture; 3 is standard for the shaft |
| `patient_weight` | kg; load = weight × gait factor (§1) |
| `species` | see below |

**Species handling.** The pipeline is species-agnostic because the input is just a mesh,
but three things scale:

- Load: `patient_weight × gait_factor`. Use 3.0 for human and dog walking unless the
  prescription overrides it.
- Screw diameter must scale with cortical thickness. Measure local cortical thickness
  from the mesh rather than assuming 3.5 mm — a toy-breed dog radius will not take a
  human-sized screw.
- The stiffness band scales with the bone's own stiffness. A band tuned for a human tibia
  is wrong for a bird humerus. If the prescription does not supply a band, derive one
  from the bone's section properties and **log that you did so**.

If a combination is clinically invalid (per §2, bridging on a simple transverse
fracture), that is a design error to report, not a parameter to tune around.

---

## 12. Definition of done

A run succeeds when a valid STEP file passes every check in §6 with an iteration log
recording each change and its rationale. Ties are broken by lower mass, then by fewer
iterations.

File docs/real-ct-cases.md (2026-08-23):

# Running a real CT-derived case

The synthetic femur in `inputs/` is the default quick-start path and is unchanged.
This document covers the other path: designing against a bone segmented from real
CT imaging.

The split is deliberate. This repo designs an implant *around a surgical plan*; it
does not decide where screws go in a patient. So a real case arrives as two
things — a segmented bone mesh and a surgical plan — and the importer's job is to
refuse a plan it cannot design against rather than invent the missing half.

## The two phases

| Phase | Input | Command |
|---|---|---|
| 1 | Segmented mesh + surgical plan | `autoimplants.import_case` |
| 2 | Raw DICOM series | `autoimplants.dicom_to_mesh`, then phase 1 |

Phase 2 is optional research tooling. Threshold segmentation produces a plausible
bone, not a correct one — a human has to look at it before it becomes a case.

## Phase 1: mesh plus plan

```bash
python -m autoimplants.import_case \
    --case real_cases/example/surgical_plan.json \
    --bone real_cases/example/bone.stl
```

That writes a self-contained case:

```
real_cases/<case_id>/generated/
    bone.stl                 the mesh, rigidly transformed into the repo frame
    case.json                thresholds, envelope, material, input paths
    screw_positions.json     locked planning input, in the repo frame
    keepout_zones.json       locked planning input, in the repo frame
    frame_transform.json     the 4x4 that was applied, for traceability
    import_report.json       every check the import ran
```

Run it exactly like the synthetic case:

```bash
python -m autoimplants.run \
    --case real_cases/<case_id>/generated/case.json \
    --validators geometry,fea
```

### Why not `inputs/`

`harness/guard.py` locks `inputs/*` as system-controlled — case constraints and
anatomy are not the agent's to edit. A case imported into that directory would
show up as a guard violation on the agent's own diff, so imports land in
`real_cases/` instead and the case file is passed with `--case`.

### The coordinate frame

Everything downstream of the importer assumes:

- **+Z** along the shaft, proximal to distal, origin at the proximal landmark
- **+X** the aspect the plate mounts on
- **+Y** the plate width direction

Real segmentations arrive in scanner coordinates: obliquely angled, origin at the
isocentre. Rejecting those would make real-CT support useless, since no scanner
produces an axis-aligned bone. So the importer *computes* the transform from the
landmarks in the plan and applies it to the mesh, the screws and the keepouts
together. Relative geometry is untouched — it is a change of description, not of
anatomy — and the matrix is written to `frame_transform.json` so the mapping back
to the source scan is never lost.

## The surgical plan

`real_cases/example/surgical_plan.json` is the worked example. Required fields:

| Field | Meaning |
|---|---|
| `case_id` | Identifier; names the output directory |
| `bone` | `femur`, `tibia`, … — sets the plausible-size bounds for the mesh gate |
| `side` | `left` / `right` |
| `approach` | Which aspect the plate mounts on, e.g. `lateral` |
| `coordinate_frame` | `landmarks` (three points) or explicit `axes` |
| `footprint_z_mm` | `[z_start, z_end]` of the plate, in the repo frame |
| `screws` | `id`, `entry_mm`, `direction`, `diameter_mm`, `length_mm` |
| `keepouts` | Spheres: `id`, `center_mm`, `radius_mm`, `rationale` |
| `material` | At minimum `name` and `density_g_cm3` |
| `thresholds` | The limits the validators enforce |

Landmarks, when used, are three points in the same frame as the mesh:

- `proximal_shaft_mm` — becomes the origin, and the `-Z` end of the shaft axis
- `distal_shaft_mm` — the `+Z` end
- `mount_side_mm` — any point on the aspect the plate mounts on, well clear of
  the axis

Screw `direction` need not be normalised; only the zero vector is an error.
Directions are not required to be axis-aligned — the geometry validator casts
each bore check along the screw's own trajectory.

A missing field is an error naming the field, never a default. That is the whole
point: an incomplete plan that imports anyway produces an implant fitted to
numbers nobody supplied.

## What the import checks

**The mesh** (`autoimplants/mesh_quality.py`) — none of these can be produced by
`inputs/make_bone.py`, which is exactly why the gate exists:

- non-empty and readable
- plausible size for the named bone, measured across the convex hull so an
  obliquely posed mesh is not mistaken for a short one
- single component; speckle islands are dropped, two comparably sized components
  fail for human review
- watertight, repairing holes where it can — containment queries are undefined on
  an open surface
- within the ray-casting face budget, decimating if `fast-simplification` is
  installed

**The plan against the bone** (`autoimplants/surgical_plan.py`):

- every screw entry lies on the bone surface (2.5 mm tolerance)
- every trajectory passes through bone, with the thinnest purchase reported
- the plate footprint lies on the shaft that exists in this mesh
- every screw falls inside that footprint

Those four catch a structurally perfect plan that refers to a *different scan* —
before the design loop spends its whole iteration budget on geometry that was
never seated on the bone.

## Phase 2: raw DICOM

```bash
python -m autoimplants.dicom_to_mesh \
    --dicom-dir <one-series-directory> \
    --bone femur \
    --out real_cases/<case_id>/bone.stl
```

The DICOM stack (`pydicom`, `SimpleITK`, `scikit-image`, `scipy`) ships in
`requirements.txt`, so `bash setup.sh` is the only install step. It is by far the
heaviest thing in there — about 255 MB — and nothing in the design loop imports
it, so `dicom_to_mesh` imports it lazily: a broken DICOM install can never stop
`autoimplants.run` from working.

What the tool does: reads one series with its real spacing and orientation,
converts to Hounsfield units, thresholds at a conservative 300 HU cortical value,
keeps the largest connected component, closes pinholes, and surfaces it with
marching cubes **in patient coordinates**. It then runs the same mesh gate a
hand-segmented mesh must pass.

It refuses a directory holding more than one series rather than picking one —
that is how you segment the scout scan by accident.

### Patient data

- **De-identify before the data reaches this machine.** The tool reports which
  direct identifiers are still populated (`PatientName`, `PatientID`,
  `AccessionNumber`, …) and does not strip them: de-identification is the data
  owner's decision and their audit trail.
- **Never commit DICOM to this repository** — for privacy first, size second.
- Threshold segmentation is research/demo tooling. It is not clinical
  segmentation and carries no clinical, FDA, ISO or ASTM claim.

## Placing the landmarks

After a CT conversion the mesh is in patient coordinates -- origin at the scanner
isocentre, axes unrelated to the bone -- so the three landmarks cannot be guessed
and reading them off a viewer one at a time is slow and error-prone.

```bash
python -m autoimplants.landmarks     --bone real_cases/<case_id>/bone.stl     --mount-side +x     --case-id <case_id> --out real_cases/<case_id>/surgical_plan.json
```

It fits the diaphyseal axis from cross-section centroids (not a vertex-cloud PCA,
which the condyles drag off-axis) and places the two shaft landmarks at 15% and
85% of the bone's length.

Two things it cannot decide, and reports rather than hides:

- **Which end is proximal.** Guessed from which end is bulkier. Right for a
  femur, wrong for other bones and for partial scans -- pass `--flip`.
- **Which way the plate mounts.** Pure anatomy. You supply it with
  `--mount-side`.

The plan it writes is **deliberately incomplete**: no screws, no keepouts, and
placeholder material and thresholds. `import_case` rejects it until a human fills
those in from real surgical planning. A tool that scaffolded a plausible-looking
plan would be the easiest way to smuggle fabricated clinical data into a case.

## Testing the pipeline without patient data

```bash
python real_cases/synthetic_ct/make_ct.py
```

Writes a femur-shaped CT phantom -- a real DICOM series, ~27 MB, not committed
and regenerated in seconds. It is rendered *from* `inputs/bone.stl` under a stated
pose, so the correct reconstruction is known exactly and can be scored instead of
eyeballed.

It is built to have the properties that break real scans, one per failure it
catches:

| property | what it catches |
|---|---|
| cortical shell around a marrow canal | thresholding must find the cortex, not the whole limb |
| surrounding soft tissue | a 300 HU cut has to actually separate them |
| acquisition noise | morphological cleanup has to survive speckle |
| oblique direction cosines | the index-to-patient affine, applied the right way round |
| anisotropic voxels (0.8 x 0.8 x 1.25 mm) | a transposed spacing vector distorts the anatomy |

Measured end to end on that phantom:

- surface deviation from ground truth: **0.128 mm mean, 0.30 mm p95** against
  0.8 mm voxels
- screw entries land **0.2 mm** from the reconstructed surface (2.5 mm tolerance)
- the resulting design's bone gap is **8.46 mm**, against 8.60 mm on the exact
  mesh -- the difference is the reconstruction error, as it should be

One thing the phantom exposed that the unit tests could not: a thresholded cortex
is a *tube*, and marching cubes surfaces a tube as two shells -- the outer bone
and the wall of the medullary canal. Two components of comparable size reads as
"two bones in the field of view" to a naive count. The gate now detects nested
shells and keeps the outer surface.

## Validating against a public dataset

Reproducible, no patient data, not committed here:

1. Prefer a dataset carrying **both imaging and segmentations/landmarks**, so the
   plan can be built from published landmarks rather than guessed — whole-femur CT
   collections with segmentation labels are the best fit.
2. The Visible Human lower-extremity CT plus its derived STL assets is the easier
   fallback when a segmented dataset is hard to obtain.
3. Download outside the repo, convert with `dicom_to_mesh`, scaffold the frame
   with `autoimplants.landmarks`, fill in the planning data from the published
   landmarks, then import.

This step is manual and local by design: the datasets are far too large to commit
and their licences differ.

## Tests

```bash
python -m pytest tests -q
```

The import path is round-tripped against a known answer. `real_cases/example/` is
the synthetic femur rigidly transformed into an arbitrary scanner-like pose, so
the importer has to recover a frame whose correct result is exactly `inputs/` —
any error in the frame recovery shows up as a millimetre-scale disagreement with
the ground truth. Regenerate it with:

```bash
python real_cases/example/make_example.py
```

DICOM tests skip cleanly when the DICOM stack is absent, so the suite still runs
on a machine that only installed the design-loop dependencies.

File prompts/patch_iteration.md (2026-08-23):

# Iteration prompt template — posted-file mode

Used when the design agent runs as part of the local application instead of
against a Git branch: the server posts it the files to work on and validates
whatever it posts back. Nothing is committed and nothing is pushed.

Placeholders are substituted with `str.replace`, **not** `str.format` — the
report contains JSON braces and escaping them all would be a source of silent
bugs.

Tokens: `{{ITERATION}}` `{{REPORT}}` `{{PARAMS}}` `{{HISTORY}}` `{{JOB_URL}}`
`{{SOURCES}}` `{{CASE}}`

---

You are a mechanical engineer working on a patient-specific orthopaedic bone
plate. Your job is to change the design until it passes every validation check.

Iteration: `{{ITERATION}}`
Patient case under design: `{{CASE}}`

You are not working in a Git repository and you must not commit, push or open a
pull request. The application posts you the source it wants changed, and it runs
the validators for you on whatever you post back.

## Your job endpoint

```
{{JOB_URL}}
```

`GET` it for the current job: the source files you may change, the patient case
bundle, the failing checks, and — after every submission — the validator report
for what you posted.

`POST` the same URL to submit a design, as JSON:

```json
{
  "files": {"autoimplants/generator.py": "<the complete new file contents>"},
  "rationale": "<the engineering note described below>",
  "topology_changed": true
}
```

Send whole files, not diffs, and only files from the editable list. Then `GET`
the URL every few seconds: `status` moves `awaiting_patch` → `validating` →
`report_ready`, and `report` then holds the validators' own measurements of your
geometry. If checks still fail, edit again and `POST` again — each submission is
one recorded iteration, and the run stops when the geometry converges or the
iteration budget runs out.

Set `"infeasible": true` only if you believe no legal design can pass; say why in
the rationale.

## What failed

```
{{REPORT}}
```

Current parameters:

```json
{{PARAMS}}
```

What has already been tried on earlier iterations:

```
{{HISTORY}}
```

## What you may change

The job payload carries the current contents of exactly these files:

{{SOURCES}}

Locked — the server rejects a submission that contains any other path:

- the patient case bundle: anatomy, surgical plan, load cases, pass thresholds.
  Screw positions and keepout zones are pre-solved surgical planning input. The
  implant accommodates them; they do not move.
- `autoimplants/validators/**` — you do not get to rewrite your own examiner.
- `autoimplants/bone.py` — the validator measures the bone gap through this
  module. Editing it changes the measurement instead of the design.
- `autoimplants/contracts.py`, `harness/**`, `tests/**`.

Changing a threshold is not a fix.

## Important: parameters alone will not work

`params` declares four topology handles — `thickness_profile`, `ribs`,
`hole_slots`, `contour_spline` — and `build_implant()` **raises
NotImplementedError** if you set one without implementing it. That is intentional.
To use a handle you have to write the geometry in `generator.py` and flip the
corresponding `*_IMPLEMENTED` flag. The docstring in `_guard_unimplemented`
describes how each one is meant to work.

Before reaching for a scalar tweak, check it can actually succeed. The design
space is genuinely constrained:

- Uniform thickening is capped by the implant mass budget.
- Widening is blocked by a keepout zone at mid-span.
- Lengthening is blocked by keepout zones at both ends.

If the arithmetic says a scalar change cannot close the gap, change the geometry
instead.

## Reading a stress failure

`fea_max_von_mises` is a real linear-static solve on your posted geometry, not a
formula: the report's `location` is the node where the peak was measured and the
run also writes `stress_field.json`, a per-vertex field of the same solve. Fix it
where the solve says the stress is, not where you assume it is — moving material
to a section that is already lightly loaded spends mass budget for nothing.

The peak is read away from the screw bores on purpose: the solve restrains those
nodes rigidly, so stress there is a boundary-condition artefact that grows with
mesh refinement and means nothing about your design. Do not tune against it.

The model idealises: rigid screws, no bone sharing the load, one static case, no
fatigue. Treat it as a comparative measure between your candidates.

## The rationale you submit

It is a real engineering deliverable — it becomes the design history for this
part — so write it for the engineer who inherits the design:

```
<short summary of the geometric change>

Failure addressed: <check id> measured <value> <unit> against a <limit> limit.
Change: <what you changed in the geometry, and why that addresses the mechanism>
Rejected: <what you considered and why it could not work>
Result: <the check values you expect after your change>
```

State the mechanism, not just the edit. "Added a 30 mm rib at mid-span" is an
edit; "added a rib at mid-span because peak bending moment is there and local
section modulus scales with height squared, so 1.1 g of material buys what 18 g of
uniform thickening would" is engineering.

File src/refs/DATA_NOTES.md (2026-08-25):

# Data notes — what is actually in `src/data`, verified by inspection

Everything below was checked against the downloaded files, not read off a
portal page.

## Findings

1. **TotalSegmentator has no tibia**, despite portal claims of "117 structures
   incl. tibia". The most distal bone in the v2 label set is
   `femur_left` / `femur_right` (75/76); the list ends at ribs, sternum and
   costal cartilages. Tibia lives in TotalSegmentator's separate
   `appendicular_bones` subtask, which is **not part of this 1228-CT
   dataset**. On top of that, the scans are mostly thorax/abdomen/pelvis, so
   the lower leg is usually outside the field of view. The "we also handle
   raw CT" story does not work off this dataset as written — it needs
   lower-limb CT plus the `appendicular_bones` task, and that task's model
   weights carry their own licence.

2. **MedShapeNet is not a usable programmatic source right now.** Its Python
   API serves only "showcase" samples from a MinIO bucket; the bulk archive
   is waiting on storage (the maintainers' own README says so). The portal
   responds, but plan on manual download at most. The Hugging Face mirror is
   empty; the API is the same story.

3. **The shape models are MATLAB `.mat`, and all the dataset's own code is
   MATLAB** (GIBBON, geom3d, export_fig). That is not a blocker — see below —
   but nothing in the dataset runs as shipped without MATLAB.

4. **`paed_ssm` is account-gated, not merely "not yet pulled", and is not a
   near drop-in for `fetch_ssm_tibia.sh`.** `ssm_tibia` downloads anonymously from **figshare**; `paed_ssm`
   exists only on **SimTK**, whose `frs/download_confirm.php` redirects to
   `/account/login.php`. No figshare or Zenodo mirror exists (both searched via
   their APIs). It needs a free SimTK account and a scraped per-session
   `form_key` CSRF token — `fetch/fetch_paed_ssm.sh` does this. The login and
   failure paths are tested; the authenticated download is not, because no
   credentials exist yet.

Net effect: **`ssm_tibia` is not just the primary source, it is effectively
the only tibia source.** The SSM sampling path is what backs "five unseen
anatomies", so it carries more weight than the brief assumes.

## ssm_tibia — verified contents

550,603,776 bytes, md5 `c92d24cf00609b44f5fddd5727a0120e`, figshare v4,
CC-BY-4.0. Unpacks to ~1.1 GB, 445 STLs.

```
Segmentation/case-<id>/     30 cases, ages 19–40
  <id>-tibia-cortical.stl          ~39.6k tris, ~353 mm long   <- the build target
  <id>-tibia-cortical-remesh.stl   ~20.7k tris, evenly remeshed <- cheaper for FEA
  <id>-tibia-trabecular.stl        ~10.5k tris, inner boundary  <- screw purchase
  <id>-fibula.stl                  ~16.8k tris
  <id>-TP.stl                      tibial plateau patch, ~65x44x13 mm
  <id>-AJ.stl                      ankle joint patch, ~31x32x5 mm
  LC/LM/MC/MM.txt                  single landmark points, UTF-16 XML
                                   (Materialise/Mimics format, not plain text)
  tibial-plateau.xml               plateau definition
ShapeModels/{tibia,tibia-fibula,tibia-plus-trabecular,trabecular-tibia}/
  *ShapeModel.mat                  the model
  *ShapeModel_mean.stl             mean surface (point order differs from .mat)
Data/participant-characteristics.csv   age, weight, height
Data/registeredSurfaceDataPoints.mat   pre-registered points (skips a 1–2 h step)
Examples/case{1,2,3}/            MATLAB: sample a population; predict trabecular;
                                 reconstruct from palpable landmarks
Code/                            MATLAB SSM construction + supplementary deps
```

Two small snags: the participant CSV has **32 rows for 30 cases** — ids
`134065` and `172501` have no segmentation folder, so join on the case dirs,
not the CSV. And the CSV has **no sex column**, so the 20M/10F split cannot
be recovered from the data itself (it is in the paper).

## The shape model, read from Python — verified working

`src/ssm/load_ssm.py`. `scipy.io.loadmat` reads the `.mat` directly
(pre-v7.3, no h5py). No MATLAB anywhere in the path.

Tibia model: 3500 points, 6996 triangles, 29 PCs, **5 retained = 90.3 % of
variance**. Fields: `mean` (1, 10500), `loadings` (10500, 29) with unit-norm
columns, `latent` (29,), `score` (30, 29), `F` (6996, 3) **1-based, MATLAB
convention — convert before use**. Point layout is x,y,z interleaved per
point, so a plain row-major `reshape(3500, 3)` is correct.

Validation actually run:

- `mean + loadings @ score[i]` reproduces training surface `nodes[i]` to
  **1e-13** — the reconstruction math is confirmed, not assumed.
- Truncating to the 5 retained PCs costs **≤3.7 mm** max point error on
  case 0, consistent with the paper's reported error.
- `sqrt(latent)` equals the column std of `score`, so sampling weights in
  units of standard deviation is the right scaling.
- Sampled surfaces measure ~72 x 397 x 72 mm — a plausible tibia.

Two traps. The stored `reconstructed` array is in a **different, recentred
frame** (values near the origin) — do not diff it against your own
reconstruction, it will look 400 mm wrong when nothing is. And on macOS the
Accelerate BLAS raises spurious divide-by-zero/overflow flags on this matmul
even though every input is finite; the loader suppresses them deliberately.

## totalsegmentator_lite — verified contents

1228 merged mask volumes (`Masks/s*.nii.gz`), 902 MB extracted, plus
`meta.csv` (age, sex, institute, study type, scanner, pathology) and the
mirror's own README carrying the full 117-label map. Images (22.6 GB) not
downloaded — `fetch/fetch_totalsegmentator_lite.sh --with-images`.

Given correction 1, treat this as a **test fixture for the mask -> mesh ->
mesh-check path** (femur is at least a long bone), not as tibia geometry.

## Not obtained

- **PeerJ 14708 PDF** — peerj.com returns 403 to scripted fetches. Open
  access in a browser; cited in `CITATIONS.md`.
- **ASTM F382** — paywalled, ~$70. Output stays labelled "F382-style".
- **NMDID source CTs** — registration required, not redistributable, and not
  needed: the derived meshes are the open part.
- **`paed_ssm` files** — `Lower_limb_bone_pred.zip` (137 MB) and
  `Clinical_bone_measurements.zip` (220 KB). Behind a SimTK login, so no bytes
  and therefore **no pinned checksum**; `fetch_paed_ssm.sh` prints the md5 it
  receives so the first successful run can pin it.

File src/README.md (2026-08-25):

# src — the resources this build runs on

Downloaded, checksum-verified and inspected. Read
[refs/DATA_NOTES.md](refs/DATA_NOTES.md) for the verified inventory.

## Layout

```
src/
├── README.md                   this file
├── env/doctor.py               verify imports + ccx + data (`pixi run doctor`)
├── ssm/load_ssm.py             read the shape model from Python, sample anatomies
│
├── fetch/
│   ├── fetch_ssm_tibia.sh              primary data, md5-verified, idempotent
│   ├── fetch_paed_ssm.sh               target population (ages 4–18); needs SimTK login
│   └── fetch_totalsegmentator_lite.sh  secondary; --with-images for the 22.6 GB
│
├── refs/
│   ├── DATA_NOTES.md           verified inventory
│   └── CITATIONS.md            CC-BY attribution, a licence condition
│
└── data/                       gitignored (3.2 GB: 2.0 GB extracted + 1.3 GB archives)
    ├── ssm_tibia/              30 tibia-fibula cases + 4 shape models
    ├── paed_ssm/               paediatric SSM, ages 4–18 — empty until credentials
    ├── totalsegmentator_lite/  1228 CT mask volumes + metadata
    └── _downloads/             the source archives, kept for re-extraction
```

`data/` is deliberately gitignored. The fetch scripts are the reproducible part; the 2 GB is
not. Both scripts skip a download that is already present, so re-running is
cheap.

## Have / haven't

| Resource | Status |
|---|---|
| `ssm_tibia` meshes + SSM | **downloaded**, md5 verified, 445 STLs, 1.1 GB |
| SSM readable without MATLAB | **verified** — reconstructs training surfaces to 1e-13 |
| `paed_ssm` (ages 4–18) — *target population* | 🔑 **script ready, account-gated.** Needs `SIMTK_USER`/`SIMTK_PASS`; login flow tested, download unexercised |
| TotalSegmentator masks | **downloaded**, 1228 volumes — but **no tibia label** |
| TotalSegmentator CT images | not downloaded, 22.6 GB, script ready |
| MedShapeNet | **unusable programmatically** — API serves samples only |
| Python toolchain | **installed + locked** via `../pixi.toml` (cadquery 2.8.0, see note) |
| CalculiX `ccx` | **installed** — conda-forge 2.23, part of the locked env |
| ASTM F382 | paywalled, not obtained — output stays "F382-style" |
| PeerJ paper PDF | 403 to scripted fetch; open access in a browser |

## Quick start

```bash
pixi install          # whole toolchain incl. the ccx solver, from ../pixi.lock
pixi run setup        # doctor + fetch data + sample 5 unseen anatomies to STL
```

`pixi run setup` is the one command: it verifies imports and that `ccx` is on
PATH, fetches the adult SSM data (~550 MB, resumable, md5-checked), then writes
the mean plus 5 unseen anatomies as STL — the cheapest end-to-end check that the
primary data is intact and usable. The steps are separately runnable as
`pixi run doctor`, `pixi run fetch-ssm`, `pixi run ssm-sample`.

**The target population needs one extra step.** `paed_ssm` (children, ages 4–18)
is the second anatomy source and the one that matches the market. It is not in
`setup` because SimTK gates it behind a login and there is no anonymous mirror:

```bash
# register free at https://simtk.org/account/register.php, then
export SIMTK_USER=... SIMTK_PASS=...      # or put them in .env
pixi run fetch-paed
```

CalculiX comes from conda-forge as part of the locked environment. See
[../pixi.toml](../pixi.toml) for the complete toolchain and the CadQuery 2.8.0
compatibility rationale.

## Why the SSM matters more than the brief assumes

The "five unseen anatomies, live" claim rests entirely on sampling the shape
model, because `ssm_tibia` is effectively the only tibia source we have:
TotalSegmentator does not label the tibia, and MedShapeNet cannot be pulled
programmatically. The good news is that the sampling path is verified working
from plain Python — 5 principal components, 90.3 % of variance, weights in
standard deviations, mesh topology shared across every sample (so any
plate-fitting logic written against the mean surface transfers to samples
without re-registration).

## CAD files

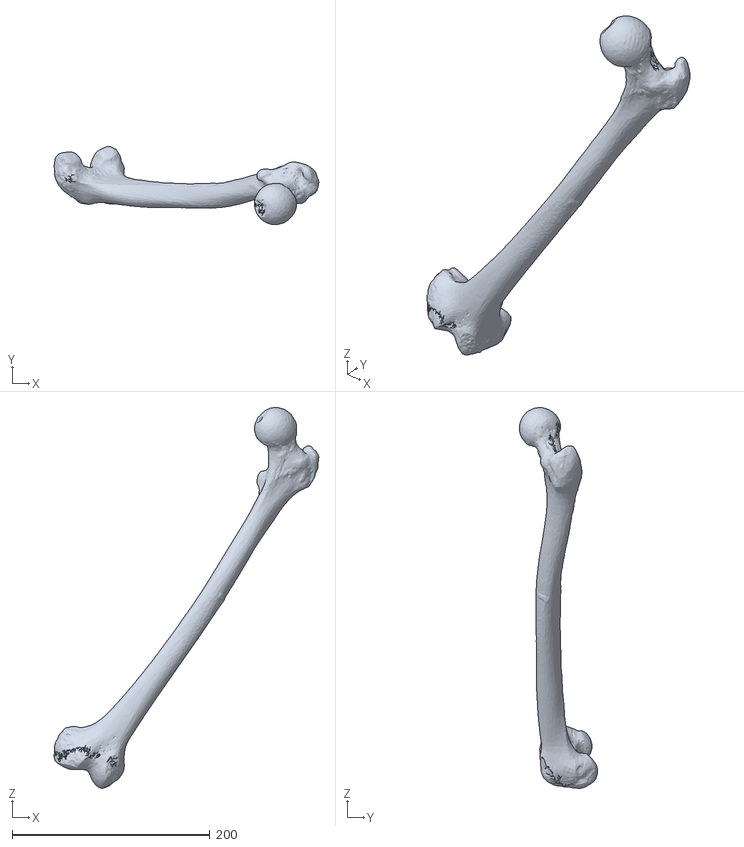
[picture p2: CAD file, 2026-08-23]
autoimplants/assets/human_femur_hero.stl
267.4 x 79.0 x 384.9

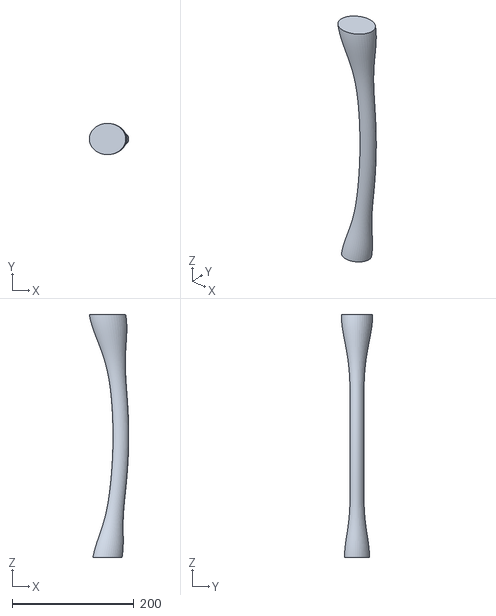
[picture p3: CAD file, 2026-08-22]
inputs/bone.stl
65.0 x 51.6 x 400.0

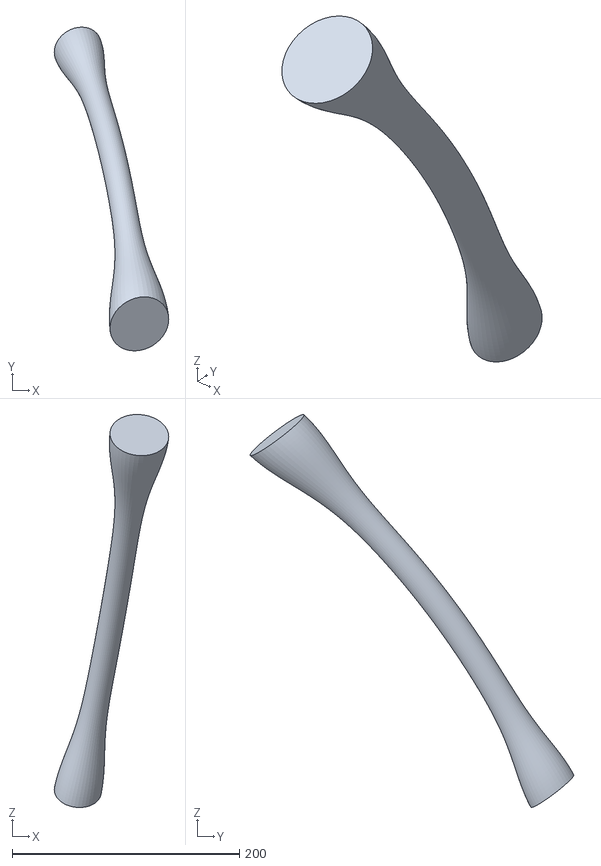
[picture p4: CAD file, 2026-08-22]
real_cases/example/bone.stl
100.9 x 285.2 x 346.1

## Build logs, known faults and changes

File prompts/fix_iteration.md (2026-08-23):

# Iteration prompt template

Placeholders are substituted with `str.replace`, **not** `str.format` — the report
contains JSON braces and escaping them all would be a source of silent bugs.

Tokens: `{{ITERATION}}` `{{REPO_URL}}` `{{BRANCH}}` `{{REPORT}}` `{{PARAMS}}` `{{HISTORY}}`

---

You are a mechanical engineer working on a patient-specific orthopaedic bone
plate. Your job is to change the design until it passes every validation check.

Repository: `{{REPO_URL}}`
Work on branch: `{{BRANCH}}`
Iteration: `{{ITERATION}}`

## What failed

```
{{REPORT}}
```

Current parameters:

```json
{{PARAMS}}
```

What has already been tried on earlier iterations:

```
{{HISTORY}}
```

## What you may change

Editable — this is the design surface:

- `autoimplants/generator.py` — the CAD generator. **This is the file that matters.**
- `autoimplants/params.py` — default parameter values.
- `autoimplants/export.py` — export settings.
- `runs/` and `out/` — write your artefacts and build output here.

Locked — do not modify, and do not work around:

- `inputs/**` — the anatomy, the surgical plan, the load cases, the pass
  thresholds. Screw positions and keepout zones are pre-solved surgical planning
  input. The implant accommodates them; they do not move.
- `autoimplants/validators/**` — you do not get to rewrite your own examiner.
- `autoimplants/bone.py` — the validator measures the bone gap through this
  module. Editing it changes the measurement instead of the design.
- `autoimplants/contracts.py`, `harness/**`.

A commit that touches a locked file makes the iteration invalid, and this is
checked mechanically after every session. Changing a threshold is not a fix.

## How to check your own work

```bash
bash setup.sh                                              # first time only
.venv/bin/python -m autoimplants.run --validators geometry,fea
```

Exit code 0 means the design passes; 1 means it does not. Read the failure table:
every check gives you a measured value, the limit it broke, and where in the part
it happened. Use the location — the numbers are there so you do not have to guess.

Re-run after every change. Do not commit a design you have not validated.

## Important: parameters alone will not work

`params` declares four topology handles — `thickness_profile`, `ribs`,
`hole_slots`, `contour_spline` — and `build_implant()` **raises
NotImplementedError** if you set one without implementing it. That is intentional.
To use a handle you have to write the geometry in `generator.py` and flip the
corresponding `*_IMPLEMENTED` flag. The docstring in `_guard_unimplemented`
describes how each one is meant to work.

Before reaching for a scalar tweak, check it can actually succeed. The design
space is genuinely constrained:

- Uniform thickening is capped by the implant mass budget.
- Widening is blocked by a keepout zone at mid-span.
- Lengthening is blocked by keepout zones at both ends.

If the arithmetic says a scalar change cannot close the gap, change the geometry
instead.

## Committing

One commit per design change. The commit message is a real engineering
deliverable — it becomes the design history file for this part — so write it for
the engineer who inherits this design:

```
<short summary of the geometric change>

Failure addressed: <check id> measured <value> <unit> against a <limit> limit.
Change: <what you changed in the geometry, and why that addresses the mechanism>
Rejected: <what you considered and why it could not work>
Result: <the check values after your change>
```

State the mechanism, not just the edit. "Added a 30 mm rib at mid-span" is an
edit; "added a rib at mid-span because peak bending moment is there and local
section modulus scales with height squared, so 1.1 g of material buys what 18 g of
uniform thickening would" is engineering.

Then report the structured output.

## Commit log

2026-08-22 Freeze contracts + stub failing validator
    Unblocks all four lanes before any real geometry exists.
    - contracts.py: Report/Check, frozen. The agreed {passed, checks[]} shape is an
    exact subset; iteration/params/meta are additive with defaults. Report.summary()
    renders the failure table that gets pasted into Devin's prompt, so it is a real
    interface, not a debug print.
    - validators/: lazy-imported registry. A validator that raises becomes an ERROR
    check rather than a traceback -- one bad geometry must not kill the loop.
    - validators/stub.py: hardcoded FAILING report so the harness and demo lanes can
    build now. Dependency-free on purpose: runs on any interpreter.
    - params.py: DEFAULT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
2026-08-22 Commit synthetic femur + locked case constraints
    Inputs are procedural, not downloaded: make_bone.py regenerates bone.stl
    deterministically, so there is no licence question and the anatomy is diffable.
    Screw positions are sampled ON the generated surface rather than hand-typed --
    otherwise the geometry validator would be checking the implant against numbers
    that never touch the bone.
    The 22 mm anterior bow (sagitta over 400 mm => 0.91 m radius of curvature, inside
    the published femoral range) is what makes the generic FLAT plate fail on this
    patient: measured 4.87 mm of mid-span standoff against a 1.5 mm limit. The opening
    failure of the demo is designed in, not discovered at runtime.
    Non-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
    [bone.stl]
2026-08-22 Wire the loop end to end: generator, validators, Devin harness, docs
    The baseline plate now builds, exports, and fails on real measured geometry
    rather than a stub: 8351 mm^3 / 37.0 g, one failing check out of twenty --
    bone_conformance_gap at 6.17 mm against a 1.5 mm limit. That is the opening beat
    of the demo, and it is measured, not asserted.
    generator.py is the file Devin edits. It refuses to silently ignore a topology
    parameter: setting ribs/thickness_profile/hole_slots/contour_spline without
    writing the geometry raises NotImplementedError with instructions. This is the
    mechanism that makes parameter-tuning structurally impossible rather than merely
    discouraged -- Devin has to write co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
2026-08-22 Initial commit for prototype01
    Entire-Checkpoint: 01M0NDC35JEGNCYT055J3V18S0
2026-08-22 docs: plan real CT case ingestion
2026-08-22 Add the CT Ingestion layer
    Entire-Checkpoint: 01M0NRHAN43YRATTWGZ20RHPBC
    [bone.stl]
2026-08-22 Retune the case so a design can exist without a scalar one existing
    The stress validator now measures instead of asserting, and at the old
    thresholds it showed the case had no solution at all. Sweeping the full
    legal space -- width to the 17.6 mm keepout limit, thickness to the
    5.6 mm the 6.0 mm standoff cap allows -- the lightest design meeting
    350 MPa weighed 92 g against a 39 g cap. Devin would have spent its
    whole iteration budget on a case nothing could pass.
    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
2026-08-23 Contour the plate to the fitted cortex and give it a variable wall
    Change: build_implant() no longer extrudes a flat rectangle. It fits a seating
    circle to the cortex at each of 41 stations across the plate's own width lanes,
    lofts those sections along the shaft, and takes its wall thickness from
    params['thickness_profile'] instead of a single thickness_mm.
    (CONTOUR_SPLINE_IMPLEMENTED and THICKNESS_PROFILE_IMPLEMENTED now True.)
    Failure addressed: bone_conformance_gap 8.596/1.5 mm, stress_max_bending
    389.85/350 MPa and four hole checks up to 924/350 MPa on the baseline plate.
    Mechanism: the gap was transverse, not longitudinal -- the validator samples
    five lanes across the width, so a flat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
2026-08-23 Spend the wall thickness where the bending moment is
    Change: params['thickness_profile'] goes from empty (constant 3 mm) to
    2.6 mm at the ends, 3.95 mm at s=0.25/0.75 and 5.5 mm across the two inner
    screw holes (s=0.4167/0.5833, z=175/205 mm).
    Failure addressed: with the contoured plate at constant thickness the geometry
    checks passed but stress did not -- 367.52/350 MPa peak bending and inner hole
    stations up to 871.5/350 MPa.
    Mechanism: the moment profile is triangular, peaking over the fracture at
    z=190 mm and falling to zero at the outermost screws, and a plate's weakest
    station is the one through a hole. Section modulus at the four inner holes is
    therefore the only thing that matters,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
2026-08-23 Decimate the reconstructed bone to 30k faces at import
    Failure addressed: not a validator failure but a workflow one -- a run against
    the DICOM-derived case took 4m27s, which is too slow to iterate a design in.
    Mechanism: the existing quality gate already decimates; its budget was 200k
    faces, high enough that it never fired on a real reconstruction. Marching cubes
    over 0.8x0.8x1.25 mm voxels gives ~132k triangles, and profiling put 260 s of
    the 267 s inside the geometry validator's ray casts and containment queries
    against that mesh, versus 8.5 s to build the plate. Budget is now 30k.
    Chosen by measurement, not taste: at 30k the surface moves 0.0005 mm, the mesh
    stays watertight, and every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
2026-08-23 Seat on a smoothed envelope of the cortex samples, not the samples
    Failure addressed: bone_conformance_gap 4.646 / 1.5 mm on the CT-derived case,
    reported at a point where the plate is in fact 0.4 mm off the bone.
    Diagnosis: the report was reading a fold. Seating straight onto reconstructed
    samples makes neighbouring loft sections wobble against each other at the
    ~0.2 mm scale of the segmentation ripple, and the solid OpenCASCADE lofts
    through them has faces that graze and cross. Nothing announces it -- the
    tessellation still closes, so manifold_watertight passes -- but a +X ray through
    the part comes back with one hit instead of two, and the gap check measures to
    the far wall of the fold.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
2026-08-23 Hold 0.25 mm of mounting clearance instead of 0.4 mm
    Failure addressed: bone_conformance_gap 1.565 / 1.5 mm on the CT-derived case,
    with the opposite bound (bone_clearance_min) passing at 0.441 / 0.1 mm -- i.e.
    the gap budget was exhausted while the tight side had 4x the margin it needs.
    Mechanism: nominal clearance is only one of three terms in the measured gap on a
    reconstructed surface. The between-sample dilation and the smoothing lift add to
    it, and both are set by the mesh's ripple, so the nominal term is the only one
    that can be given back. 0.25 mm is still 2.5x min_bone_gap_mm, and still a
    deliberate gap rather than slop: a plate pressed onto cortex crushes the
    periosteum the fractu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
2026-08-23 Re-point the tests at the case limits, not the flat plate's numbers
    Two tests asserted the design task had not been done. Both pinned the starting
    geometry's measurements: test_synthetic_case_is_unchanged required
    implant_mass 36.996 g and bone_conformance_gap 8.596 mm -- 5.7x the case's own
    1.5 mm limit -- and test_imported_ct_case_runs_the_design_loop required the run
    to exit 1 with conformance FAIL near 8.596 mm. So the suite went red on success
    and no design could satisfy both it and the validators.
    They now assert what they were protecting: every geometry check inside the limit
    the case declares, six clear bores, no collision. That keeps the regression value
    (a plate that stops seating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
2026-08-23 Derive wall thickness from the plan's screw span, not pinned control points
    thickness_profile placed section at fixed fractions of the plate length, which
    is only correct for the screws it was tuned on. An imported case brings its own
    six entries: on a femur segmented from a public CT the inner holes landed at
    s=0.22 and s=0.78, either side of the profile's 4.5 mm peak, and reported
    362-375 MPa against a 350 limit on a 3.1 mm wall while the thickest part of the
    plate carried no hole at all.
    Two mechanisms replace the pinned profile:
    _moment_thickness derives the wall from this plan's screw span -- moment full at
    mid-footprint, zero at the outermost screws, wall rising with it. Nothing in t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
2026-08-23 Add scroll-driven bone landing experience
2026-08-23 Use realistic femur for scroll landing
    [human_femur_hero.stl]
2026-08-23 Show the running case's ID in the workbench header
2026-08-23 Clear the evidence rail until the new case has its own validation
2026-08-23 Generate implants on any bone surface, not just long-bone shafts
    The plate builder sweeps a section along a shaft axis, so anatomy without one -- a cranial vault, a scapular blade, a pelvic wall -- could not be treated at all. Adds a conformal_patch family that offsets a plan-selected region of the bone's own surface into a shell, spans interior defects with the local quadric, and drills the planned trajectories; surface-based geometry checks replace the axis-aligned ones. Stress SKIPs where there is no load model rather than reporting 0 MPa as a pass.
2026-08-23 Replace the stress placeholder with a real linear-static solve and a heatmap
2026-08-23 Let the intake page accept a plan whose family needs no footprint
2026-08-23 Solve the patch cases for real: declare their loads and unfold the shell
    Both conformal-patch demo plans now declare a load case and a stress/deflection
    limit, so the FEA validator solves them instead of reporting SKIP. Two real
    defects blocked that: the defect cut left rim vertices microns apart, whose
    extruded wall crossed the outer face and made gmsh refuse the solid, and bore
    capture was sized off the screw diameter while the generator drills a wider hole,
    so no node was restrained. Cranial passes; scapula is over wall, stress and
    deflection, and is left failing.
